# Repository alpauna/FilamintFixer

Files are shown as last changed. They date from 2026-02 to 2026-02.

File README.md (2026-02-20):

# FilamintFixer

ESP32-based automatic filament jam detector and unsticker for 3D printers. Detects when filament is jammed or pinched on the spool and mechanically yanks it free — no missed prints, no babysitting.

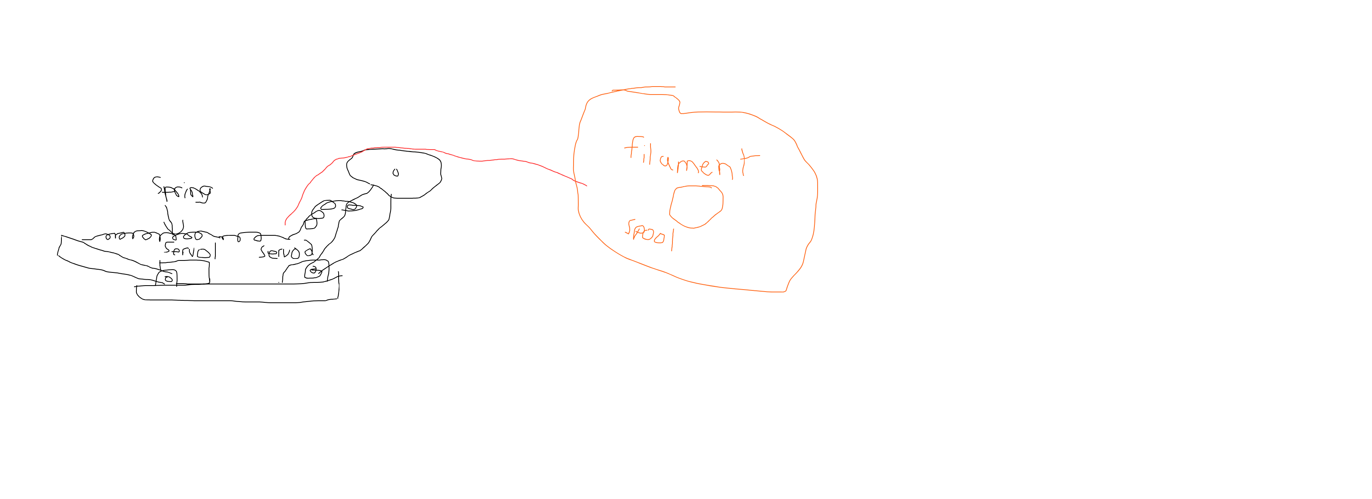
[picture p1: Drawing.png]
Concept Drawing


## How It Works

A spring-loaded feed arm guides filament from the spool to the extruder through a grooved wheel. When filament flows normally, the arm floats at its rest angle. When filament jams on the spool, the extruder's pull increases tension on the spring, pulling the arm down. When the angle drops below a threshold, a servo activates and yanks the filament free.

### Key Features

- **Automatic jam detection** via potentiometer angle feedback (primary) and reed switch filament movement detection (secondary)
- **Servo detach/attach pattern** — feed arm servo is detached during normal printing so the arm floats freely with spring tension, only attaching to actuate
- **Adjustable spring tension** — second servo locks in position to set baseline spring tension
- **Serial command interface** for tuning parameters and pot calibration
- **3D printable** — OpenSCAD parametric models included for all mechanical parts

## Bill of Materials

### Electronics (DigiKey)

| Part | DigiKey P/N | Qty | ~Price | Notes |
|---|---|-----|---|---|
| ESP32-S3-DEVKITC-1-N8R8 | [2768-ESP32-S3-DEVKITC-1-N8R8-ND](https://www.digikey.com/en/products/detail/espressif-systems/ESP32-S3-DEVKITC-1-N8R8/15295894) | 1 | $15.00 | 8MB Flash + 8MB PSRAM. Any ESP32 with ADC works |
| Standard Metal Gear Servo | [1528-1083-ND](https://www.digikey.com/en/products/detail/adafruit-industries-llc/1142/5154658) | 2 | $19.95 | Adafruit 1142. Or MG996R from Amazon (~$8/pair) |
| 10K Pot, D-shaft, Linear | [987-1308-ND](https://www.digikey.com/en/products/detail/tt-electronics-bi/P160KN-0QD15B10K/2408885) | 2 | $1.59 | TT Electronics P160KN-0QD15B10K. Must be "QD" (D-shaft) |
| Reed Switch, Glass, NO | [HE502-ND](https://www.digikey.com/en/products/detail/littelfuse-inc/MDSR-4-12-23/200302) | 1 | $1.50 | Littelfuse MDSR-4-12-23 |
| Neodymium Disc Magnet 6x3mm | [469-1017-ND](https://www.digikey.com/en/products/detail/radial-magnets-inc/8996/5126078) | 1 | $0.30 | Radial Magnets 8996 |
| 625ZZ Ball Bearing | [1188-BEARING-625ZZ-ND](https://www.digikey.com/en/products/detail/olimex-ltd/BEARING-625ZZ/21662104) | 2 | $0.82 | 5mm bore, 16mm OD, 5mm width |

### Mechanical (Amazon / McMaster-Carr)

| Part | Qty | ~Price | Notes |
|---|-----|---|---|
| Extension spring, 30-50mm, light tension | 1 | $3 | Connects feed arm to tension arm |
| M5x30mm bolt + nut | 1 | $0.50 | Guide wheel axle |
| M3/M4 screw & nut assortment | 1 kit | $12 | Mounting hardware |

**Estimated total: $45-55** (with Amazon MG996R servos) or **~$85** (all from DigiKey)

## Building

This is a [PlatformIO](https://platformio.org/) project targeting ESP32-S3.

```bash
# Build
pio run -e freenove_esp32_s3_wroom

# Upload
pio run -t upload -e freenove_esp32_s3_wroom

# Monitor serial output
pio run -t monitor -e freenove_esp32_s3_wroom
```

## 3D Printed Parts

STL files are in the `cad/` directory. Source files are parametric OpenSCAD — edit `common.scad` to adjust dimensions for different servos or potentiometers.

| Part | File | Description |
|---|---|---|
| Base | `base.stl` | Holds both servos side-by-side, pot mounting pads, reed switch mount |
| Feed Arm | `feed_arm.stl` | 120mm arm with 25T spline bore, spring anchor, wheel axle, filament retainer |
| Tension Arm | `tension_arm.stl` | 50mm arm with 25T spline bore, spring anchor at tip |
| Guide Wheel | `guide_wheel.stl` | 25mm grooved wheel with 625ZZ bearing pockets |

To regenerate STLs from source:
```bash
cd cad
openscad -o base.stl base.scad
openscad -o feed_arm.stl feed_arm.scad
openscad -o tension_arm.stl tension_arm.scad
openscad -o guide_wheel.stl guide_wheel.scad
```

## Serial Commands

| Command | Description |
|---|---|
| `u` | Manual unstick trigger |
| `t <angle>` | Set tension servo angle |
| `j <angle>` | Set jam threshold angle |
| `r <angle>` | Set rest angle |
| `c` | Pot calibration (prints raw ADC for 5 sec) |
| `s` | Print status |
| `h` | Help |

## License

MIT

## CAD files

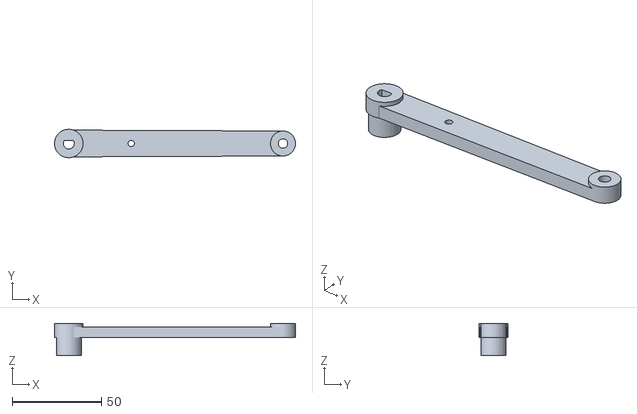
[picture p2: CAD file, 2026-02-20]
cad/feed_arm.stl
135.0 x 16.0 x 18.0

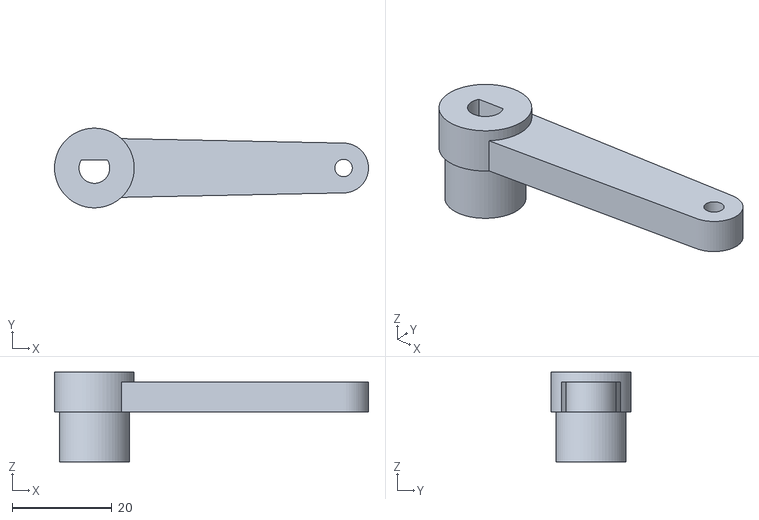
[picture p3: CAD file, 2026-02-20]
cad/tension_arm.stl
63.0 x 16.0 x 18.0

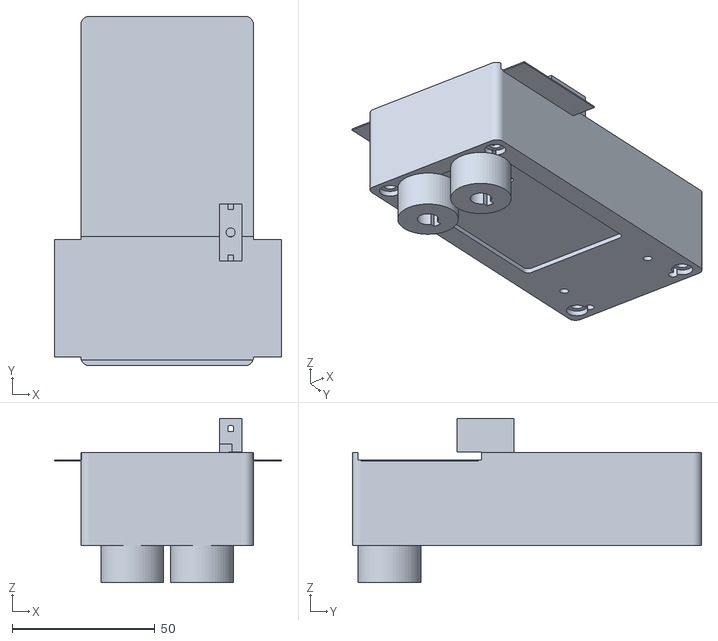
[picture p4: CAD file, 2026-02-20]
cad/base.stl
79.5 x 122.4 x 57.5

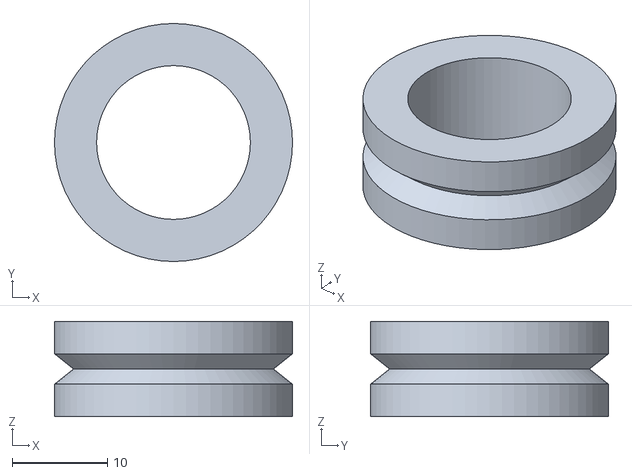
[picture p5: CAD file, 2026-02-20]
cad/guide_wheel.stl
25.0 x 25.0 x 10.0

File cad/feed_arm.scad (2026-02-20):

// feed_arm.scad — Main feed arm that attaches to Servo0
// 120mm from servo shaft to guide wheel center.
// Spring anchor point partway along the arm.
// Blind 25T spline bore couples directly to servo output shaft.

include <common.scad>

// --- Arm Parameters ---
arm_length = 120;           // shaft center to wheel center
arm_width = 15;             // arm cross-section width
arm_thickness = 6;          // arm cross-section height
hub_dia = 16;               // hub outer diameter
hub_height = 8;             // hub thickness above arm

// Spring anchor — hole for spring hook, partway along the arm
spring_anchor_dist = 35;    // distance from shaft center
spring_hole_dia = 3.5;      // spring wire hook hole

// Guide wheel axle at the tip
wheel_axle_dia = 5.0;       // axle hole diameter (for M5 bolt or 5mm shaft)
wheel_mount_dia = 14;       // boss around axle

// --- Filament Retainer ---
// L-shaped guard over the guide wheel groove to prevent filament from
// jumping out during unsticking. Bridge plate spans from boss top over
// the wheel, vertical wall drops down at the outer radius to cover the groove.
// Tapered inlet on one end for easy filament threading.

// Guide wheel references (must match guide_wheel.scad)
wheel_od     = 25;          // wheel outer diameter
wheel_width  = 10;          // wheel width (Z)
wheel_z_off  = -3;          // wheel bottom Z relative to arm Z=0 (match assembly)

// Retainer tuning
ret_gap      = 2.0;         // radial clearance between wheel rim and retainer wall
ret_wall     = 2.0;         // shell/plate thickness
ret_arc_len  = 15.0;        // arc coverage over wheel outer edge (mm)
ret_drop     = 8.0;         // how far wall drops below bridge to cover groove
ret_taper_len   = 8.0;      // inlet taper arc length (mm)
ret_taper_flare = 4.0;      // extra radial gap at taper mouth

// Derived
ret_ir       = wheel_od / 2 + ret_gap;                     // inner radius from wheel center
ret_or       = ret_ir + ret_wall;                           // outer radius
ret_arc_deg  = ret_arc_len / ret_ir * 57.2958;             // arc in degrees
ret_tap_deg  = ret_taper_len / ret_ir * 57.2958;           // taper arc in degrees
ret_bridge_z = arm_thickness + 2;                           // bridge plate Z = boss top
ret_wall_bot = ret_bridge_z - ret_drop;                     // bottom of retainer wall
ret_plate_r0 = wheel_mount_dia / 2 - 1;                    // bridge plate inner radius
ret_plate_w  = ret_or - ret_plate_r0;                       // bridge plate radial width

// Servo screw hole through hub (M3 to secure to servo horn)
horn_screw_dia = m3_hole;

// --- Filament retainer module ---
// Generates an L-shaped guard at the tip of the arm over the guide wheel.
// The bridge plate sits on the boss top (above the wheel), the vertical
// wall drops down at the outer radius to cover the groove.
module filament_retainer() {
    translate([arm_length, 0, 0]) {
        // Main arc: L-shaped cross-section swept around wheel outer edge.
        // Arc centered on +X direction (outer rim, away from arm body).
        // Single polygon avoids coincident-face manifold warnings.
        rotate([0, 0, -ret_arc_deg / 2])
            rotate_extrude(angle = ret_arc_deg)
                polygon([
                    [ret_plate_r0, ret_bridge_z],                // bridge inner bottom
                    [ret_plate_r0, ret_bridge_z + ret_wall],     // bridge inner top
                    [ret_or,       ret_bridge_z + ret_wall],     // bridge outer top
                    [ret_or,       ret_wall_bot],                // wall outer bottom
                    [ret_ir,       ret_wall_bot],                // wall inner bottom
                    [ret_ir,       ret_bridge_z]                 // L corner
                ]);

        // Inlet taper on +Y end: L-shaped cross-section flares outward.
        // Overlap 1 degree into main arc to avoid coincident-face warnings.
        hull() {
            rotate([0, 0, ret_arc_deg / 2 - 1])
                translate([ret_plate_r0, 0, ret_wall_bot])
                    cube([ret_plate_w, 0.01, ret_bridge_z + ret_wall - ret_wall_bot]);
            rotate([0, 0, ret_arc_deg / 2 + ret_tap_deg])
                translate([ret_plate_r0, 0, ret_wall_bot])
                    cube([ret_plate_w + ret_taper_flare, 0.01,
                          ret_bridge_z + ret_wall - ret_wall_bot]);
        }
    }
}

module feed_arm() {
    difference() {
        union() {
            // Hub (attaches to servo 25T spline)
            cylinder(d=hub_dia, h=hub_height);

            // Arm body — tapered from hub to wheel mount
            hull() {
                // At hub
                translate([0, -arm_width/2, 0])
                    cube([0.1, arm_width, arm_thickness]);
                // At wheel mount
                translate([arm_length, 0, 0])
                    cylinder(d=wheel_mount_dia, h=arm_thickness);
            }

            // Wheel mount boss (thicker)
            translate([arm_length, 0, 0])
                cylinder(d=wheel_mount_dia, h=arm_thickness + 2);

            // Spring anchor boss
            translate([spring_anchor_dist, 0, 0])
                cylinder(d=10, h=arm_thickness);

            // Filament retainer (guard over guide wheel groove)
            filament_retainer();
        }

        // Blind spline bore (25T servo spline coupling)
        translate([0, 0, -0.1])
            cylinder(d=servo_spline_bore, h=spline_engage_depth + 0.1);

        // Horn screw hole (through hub center, for M3 screw into servo)
        translate([0, 0, -0.1])
            cylinder(d=horn_screw_dia, h=hub_height + 0.2);

        // Guide wheel axle hole
        translate([arm_length, 0, -0.1])
            cylinder(d=wheel_axle_dia + tol, h=arm_thickness + 3);

        // Spring anchor hole (vertical, for spring hook)
        translate([spring_anchor_dist, 0, -0.1])
            cylinder(d=spring_hole_dia, h=arm_thickness + 1);
    }
}

feed_arm();

echo("=== Feed Arm ===");
echo(str("Length: ", arm_length, " mm"));
echo(str("Hub OD: ", hub_dia, " mm"));
echo(str("Spline bore: ", servo_spline_bore, " mm x ", spline_engage_depth, " mm deep"));
echo(str("Spring anchor at: ", spring_anchor_dist, " mm from shaft"));

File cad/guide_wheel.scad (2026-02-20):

// guide_wheel.scad — Filament guide wheel with groove
// Mounts at the tip of the feed arm on an axle.
// Has a V-groove to guide the filament.
// Designed for a rotary encoder or simply free-spinning on a bolt.

include <common.scad>

// --- Wheel Parameters ---
wheel_od = 25;              // outer diameter
wheel_width = 10;           // total width
groove_depth = 2.5;         // how deep the V-groove cuts into the OD
groove_width = 4;           // groove width at the rim
groove_angle = 60;          // V-groove angle

axle_dia = 5.0;             // M5 bolt or 5mm shaft
bearing_od = 16;            // 625ZZ bearing OD (if using bearing) or just clearance
bearing_h = 5;              // bearing width
use_bearing = true;         // set false for plain bore

// Encoder magnet pocket (for AS5600 or similar magnetic encoder)
magnet_dia = 6.2;           // 6mm diametric magnet
magnet_depth = 3;

module guide_wheel() {
    difference() {
        union() {
            // Main wheel body
            cylinder(d=wheel_od, h=wheel_width);
        }

        // V-groove around the circumference
        translate([0, 0, wheel_width/2])
            rotate_extrude()
                translate([wheel_od/2 - groove_depth + 0.5, 0, 0])
                    polygon([
                        [groove_depth, -groove_width/2],
                        [0, 0],
                        [groove_depth, groove_width/2]
                    ]);

        // Axle bore
        if (use_bearing) {
            // Bearing pocket (press fit from each side)
            translate([0, 0, -0.1])
                cylinder(d=bearing_od + tol_tight, h=bearing_h + 0.1);
            translate([0, 0, wheel_width - bearing_h])
                cylinder(d=bearing_od + tol_tight, h=bearing_h + 0.2);
            // Through hole for axle
            translate([0, 0, -0.1])
                cylinder(d=axle_dia + tol, h=wheel_width + 1);
        } else {
            // Plain bore with clearance
            translate([0, 0, -0.1])
                cylinder(d=axle_dia + tol*2, h=wheel_width + 1);
        }

        // Encoder magnet pocket (top face, centered)
        translate([0, 0, wheel_width - magnet_depth])
            cylinder(d=magnet_dia, h=magnet_depth + 0.1);
    }
}

guide_wheel();

echo("=== Guide Wheel ===");
echo(str("OD: ", wheel_od, " mm"));
echo(str("Width: ", wheel_width, " mm"));
echo(str("Axle: ", axle_dia, " mm"));
echo(str("Bearing: ", use_bearing ? "625ZZ" : "plain bore"));

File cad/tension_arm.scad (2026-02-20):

// tension_arm.scad — Tension arm that attaches to Servo1
// Shorter arm that anchors the other end of the spring.
// Servo1 holds this arm locked during printing to set spring tension.
// Blind 25T spline bore couples directly to servo output shaft.

include <common.scad>

// --- Arm Parameters ---
arm_length = 50;            // shorter than feed arm
arm_width = 12;
arm_thickness = 6;
hub_dia = 16;
hub_height = 8;
horn_screw_dia = m3_hole;

// Spring anchor at the tip
spring_hole_dia = 3.5;      // same as feed arm spring hole

module tension_arm() {
    difference() {
        union() {
            // Hub (attaches to servo 25T spline)
            cylinder(d=hub_dia, h=hub_height);

            // Arm body
            hull() {
                translate([0, -arm_width/2, 0])
                    cube([0.1, arm_width, arm_thickness]);
                translate([arm_length, 0, 0])
                    cylinder(d=10, h=arm_thickness);
            }

            // Tip boss
            translate([arm_length, 0, 0])
                cylinder(d=10, h=arm_thickness);
        }

        // Blind spline bore (25T servo spline coupling)
        translate([0, 0, -0.1])
            cylinder(d=servo_spline_bore, h=spline_engage_depth + 0.1);

        // Horn screw hole (through hub center, for M3 screw into servo)
        translate([0, 0, -0.1])
            cylinder(d=horn_screw_dia, h=hub_height + 0.2);

        // Spring anchor hole at tip
        translate([arm_length, 0, -0.1])
            cylinder(d=spring_hole_dia, h=arm_thickness + 1);
    }
}

tension_arm();

echo("=== Tension Arm ===");
echo(str("Length: ", arm_length, " mm"));
echo(str("Spline bore: ", servo_spline_bore, " mm x ", spline_engage_depth, " mm deep"));

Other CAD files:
cad/assembly.scad
cad/base.scad
cad/common.scad

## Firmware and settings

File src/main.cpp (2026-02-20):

#include <Arduino.h>
#include "pins.h"
#include "Config.h"
#include "WheelEncoder.h"
#include "FeedArmController.h"

Config config;
ReedSwitch reedSwitch;
FeedArmController feedArm;

uint32_t lastMonitorUpdate = 0;
uint32_t lastStatusPrint = 0;

// --- Serial Command Handler ---
//   u            - manual unstick trigger
//   t <angle>    - set tension servo angle
//   j <angle>    - set jam threshold angle
//   r <angle>    - set rest angle
//   c            - pot calibration mode (prints raw ADC values)
//   s            - print current status
//   h            - help
void handleSerial() {
    if (!Serial.available()) return;

    String line = Serial.readStringUntil('\n');
    line.trim();
    if (line.length() == 0) return;

    char cmd = line.charAt(0);

    switch (cmd) {
    case 'u':
    case 'U':
        feedArm.triggerUnstick();
        break;

    case 't':
    case 'T': {
        float angle = line.substring(1).toFloat();
        if (angle > 0) {
            feedArm.setTensionAngle(angle);
            config.tensionServoAngle = angle;
        } else {
            Serial.printf("Tension angle: cmd=%.0f° actual=%.0f°\n",
                          feedArm.tensionAngle(), feedArm.tensionArmAngle());
        }
        break;
    }

    case 'j':
    case 'J': {
        float angle = line.substring(1).toFloat();
        if (angle > 0) {
            config.feedArmJamAngle = angle;
            feedArm.updateConfig(config);
            Serial.printf("Jam threshold set to %.0f°\n", angle);
        }
        break;
    }

    case 'r':
    case 'R': {
        float angle = line.substring(1).toFloat();
        if (angle > 0) {
            config.feedArmRestAngle = angle;
            feedArm.updateConfig(config);
            Serial.printf("Rest angle set to %.0f°\n", angle);
        }
        break;
    }

    case 'c':
    case 'C':
        // Pot calibration: print raw ADC values for 5 seconds.
        Serial.println("=== Pot Calibration (5 sec) ===");
        Serial.println("Move arms to their endpoints and note the ADC values.");
        Serial.println("Update potFeedMin/Max and potTensionMin/Max in Config.h");
        for (int i = 0; i < 50; i++) {
            Serial.printf("  Feed: raw=%4d -> %.0f°  |  Tension: raw=%4d -> %.0f°\n",
                          feedArm.rawFeedPot(), feedArm.feedArmAngle(),
                          feedArm.rawTensionPot(), feedArm.tensionArmAngle());
            delay(100);
        }
        Serial.println("=== Calibration done ===");
        break;

    case 's':
    case 'S':
        Serial.println("=== Feed Arm Status ===");
        Serial.printf("  State:           %s\n", feedArmStateName(feedArm.state()));
        Serial.printf("  Feed arm angle:  %.0f° (pot raw: %d)\n",
                      feedArm.feedArmAngle(), feedArm.rawFeedPot());
        Serial.printf("  Tension angle:   %.0f° cmd / %.0f° actual (pot raw: %d)\n",
                      feedArm.tensionAngle(), feedArm.tensionArmAngle(),
                      feedArm.rawTensionPot());
        Serial.printf("  Reed pulses:     %u total, %.1f/sec\n",
                      reedSwitch.pulseCount(), reedSwitch.pulsesPerSec());
        Serial.printf("  Filament stall:  %s (last pulse %ums ago)\n",
                      feedArm.filamentStalled() ? "YES" : "no",
                      reedSwitch.timeSinceLastPulseMs());
        Serial.printf("  Unstick count:   %u\n", feedArm.unstickCount());
        Serial.printf("  Jam threshold:   %.0f°\n", config.feedArmJamAngle);
        Serial.printf("  Rest angle:      %.0f°\n", config.feedArmRestAngle);
        Serial.printf("  Unstick angle:   %.0f°\n", config.feedArmUnstickAngle);
        break;

    case 'h':
    case 'H':
    case '?':
        Serial.println("=== Commands ===");
        Serial.println("  u          - Manual unstick trigger");
        Serial.println("  t <angle>  - Set tension servo angle (spring calibration)");
        Serial.println("  j <angle>  - Set jam threshold angle");
        Serial.println("  r <angle>  - Set rest angle");
        Serial.println("  c          - Pot calibration (prints raw ADC for 5 sec)");
        Serial.println("  s          - Print status");
        Serial.println("  h          - This help");
        break;

    default:
        Serial.printf("Unknown command: '%c'. Type 'h' for help.\n", cmd);
        break;
    }
}

void setup() {
    Serial.begin(config.baudRate);
    delay(1000);

    Serial.println();
    Serial.println("================================");
    Serial.println("  3D Printer Feed Arm v0.2");
    Serial.println("  Pot Angle + Reed Switch");
    Serial.println("================================");

    // Status LED.
    pinMode(PIN_STATUS_LED, OUTPUT);
    digitalWrite(PIN_STATUS_LED, LOW);

    // Initialize reed switch (filament wheel rotation).
    reedSwitch.begin(PIN_REED_SWITCH);
    Serial.println("[Main] Reed switch initialized.");

    // Initialize feed arm controller with pot pins and reed switch.
    feedArm.begin(config, PIN_SERVO_FEED_ARM, PIN_SERVO_TENSION,
                  PIN_POT_FEED_ARM, PIN_POT_TENSION, &reedSwitch);
    Serial.println("[Main] Feed arm controller initialized.");

    Serial.println("[Main] Ready. Type 'h' for commands.");
    Serial.println();
}

void loop() {
    uint32_t now = millis();

    // Run feed arm monitor at configured interval.
    if (now - lastMonitorUpdate >= config.monitorIntervalMs) {
        feedArm.update();
        lastMonitorUpdate = now;

        // Blink LED based on state.
        if (feedArm.state() == FeedArmState::MONITORING) {
            // Slow heartbeat in normal operation.
            // Fast blink if filament stalled (warning).
            if (feedArm.filamentStalled()) {
                digitalWrite(PIN_STATUS_LED, (now / 250) % 2 == 0);
            } else {
                digitalWrite(PIN_STATUS_LED, (now / 1000) % 2 == 0);
            }
        } else if (feedArm.state() == FeedArmState::UNSTICKING ||
                   feedArm.state() == FeedArmState::HOLD_UNSTICK) {
            // Rapid blink during unstick action.
            digitalWrite(PIN_STATUS_LED, (now / 100) % 2 == 0);
        } else {
            digitalWrite(PIN_STATUS_LED, LOW);
        }
    }

    // Periodic status print (every 5 seconds).
    if (now - lastStatusPrint >= 5000) {
        Serial.printf("[Status] %s | Angle:%.0f° | Reed:%.1f/s | Unsticks:%u%s\n",
                      feedArmStateName(feedArm.state()),
                      feedArm.feedArmAngle(),
                      reedSwitch.pulsesPerSec(),
                      feedArm.unstickCount(),
                      feedArm.filamentStalled() ? " STALL" : "");
        lastStatusPrint = now;
    }

    // Handle serial commands.
    handleSerial();
}

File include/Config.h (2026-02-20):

#pragma once

#include <cstdint>

// All angles in degrees (0-160 range for 160-degree servos).
// All times in milliseconds unless noted.

struct Config {
    // --- Feed Arm ---
    // Resting angle: where the spring holds the arm under normal filament tension.
    // This is the "home" position during normal printing.
    float feedArmRestAngle = 90.0f;

    // Jam threshold: when the arm is pulled past this angle by extruder tension
    // (filament stuck on spool), trigger the unstick action.
    // Lower angle = more tension pulling the arm toward the spool.
    float feedArmJamAngle = 45.0f;

    // Unstick angle: the servo drives to this angle to yank filament away from spool.
    float feedArmUnstickAngle = 140.0f;

    // How long to hold the unstick position before returning to rest (ms).
    uint32_t unstickHoldTimeMs = 500;

    // Cooldown between unstick attempts to avoid hammering (ms).
    uint32_t unstickCooldownMs = 2000;

    // --- Tension Arm (Spring Adjustment) ---
    // Servo angle that sets the spring's effective length.
    // Higher angle = more spring compression = more tension on feed arm.
    // Adjust this to match your spool's normal drag friction.
    // Tension servo STAYS LOCKED at this angle during printing.
    float tensionServoAngle = 80.0f;

    // Min/max bounds for tension calibration.
    float tensionAngleMin = 30.0f;
    float tensionAngleMax = 130.0f;

    // --- Potentiometer Angle Reading ---
    // ADC range mapping: what ADC values correspond to 0° and 160°.
    // Calibrate by manually moving arm to known angles and reading ADC.
    uint16_t potFeedMin = 200;       // ADC value at 0° (full one direction)
    uint16_t potFeedMax = 3800;      // ADC value at 160° (full other direction)
    uint16_t potTensionMin = 200;
    uint16_t potTensionMax = 3800;

    // Potentiometer smoothing: number of samples to average.
    uint8_t potSamples = 8;

    // --- Reed Switch (Filament Movement Detection) ---
    // If no reed switch pulses within this window, filament has stalled.
    uint32_t reedStallTimeoutMs = 3000;

    // Minimum pulses per second during active printing.
    // Below this = suspicious (slow feed or stall).
    float reedMinPulsesPerSec = 0.5f;

    // --- General ---
    // How often the main monitor loop runs (ms).
    uint32_t monitorIntervalMs = 50;

    // Serial baud rate.
    uint32_t baudRate = 115200;
};

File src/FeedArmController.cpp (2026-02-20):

#include "FeedArmController.h"

const char* feedArmStateName(FeedArmState state) {
    switch (state) {
        case FeedArmState::MONITORING:   return "MONITORING";
        case FeedArmState::UNSTICKING:   return "UNSTICKING";
        case FeedArmState::HOLD_UNSTICK: return "HOLD_UNSTICK";
        case FeedArmState::RETURNING:    return "RETURNING";
        case FeedArmState::COOLDOWN:     return "COOLDOWN";
        default:                         return "UNKNOWN";
    }
}

void FeedArmController::begin(const Config& cfg, uint8_t feedServoPin,
                               uint8_t tensionServoPin, uint8_t feedPotPin,
                               uint8_t tensionPotPin, ReedSwitch* reed) {
    _cfg = cfg;
    _reed = reed;
    _feedServoPin = feedServoPin;
    _tensionServoPin = tensionServoPin;
    _feedPotPin = feedPotPin;
    _tensionPotPin = tensionPotPin;

    // Configure ADC pins for potentiometers.
    analogReadResolution(12);       // 0-4095
    analogSetAttenuation(ADC_11db); // 0-3.3V range
    pinMode(_feedPotPin, INPUT);
    pinMode(_tensionPotPin, INPUT);

    // Tension servo: attach and hold position (stays locked during printing).
    _tensionServo.setPeriodHertz(50);
    _tensionServo.attach(_tensionServoPin, 500, 2500);
    _tensionAngle = _cfg.tensionServoAngle;
    _tensionServo.write((int)_tensionAngle);

    // Feed servo: configure but start DETACHED.
    // During monitoring, the arm floats freely with the spring.
    // The pot reads the actual angle.
    _feedServo.setPeriodHertz(50);
    _feedServoAttached = false;
    // Don't attach yet — arm should float in MONITORING state.

    _state = FeedArmState::MONITORING;
    _stateEnteredAt = millis();
    _lastReedSampleTime = millis();
    _unstickCount = 0;

    // Read initial angles from pots.
    _feedArmAngle = readPotAngle(_feedPotPin, _cfg.potFeedMin, _cfg.potFeedMax);
    _tensionArmAngle = readPotAngle(_tensionPotPin, _cfg.potTensionMin, _cfg.potTensionMax);

    Serial.printf("[FeedArm] Init. Feed pot=%.0f° Tension pot=%.0f°\n",
                  _feedArmAngle, _tensionArmAngle);
    Serial.printf("[FeedArm] Jam threshold=%.0f° Unstick=%.0f° Tension cmd=%.0f°\n",
                  _cfg.feedArmJamAngle, _cfg.feedArmUnstickAngle, _tensionAngle);
    Serial.printf("[FeedArm] Feed servo DETACHED (arm floating with spring)\n");
}

void FeedArmController::update() {
    uint32_t now = millis();
    uint32_t elapsed = now - _stateEnteredAt;

    // Always read pot angles — gives actual arm position regardless of servo state.
    _feedArmAngle = readPotAngle(_feedPotPin, _cfg.potFeedMin, _cfg.potFeedMax);
    _tensionArmAngle = readPotAngle(_tensionPotPin, _cfg.potTensionMin, _cfg.potTensionMax);

    // Sample reed switch periodically.
    if (now - _lastReedSampleTime >= 1000) {
        if (_reed) {
            _reed->sample();
            _filamentStalled = _reed->isStalled(_cfg.reedStallTimeoutMs);
        }
        _lastReedSampleTime = now;
    }

    switch (_state) {

    case FeedArmState::MONITORING:
        // Feed servo is DETACHED. Arm floats with spring.
        // Pot reads actual arm angle driven by spring tension vs filament pull.
        // Jam detection: angle drops below threshold (filament pulling arm toward spool).
        if (isJamDetected()) {
            Serial.printf("[FeedArm] JAM! Arm angle=%.0f° (threshold=%.0f°) stall=%s\n",
                          _feedArmAngle, _cfg.feedArmJamAngle,
                          _filamentStalled ? "YES" : "no");
            transitionTo(FeedArmState::UNSTICKING);
        }
        break;

    case FeedArmState::UNSTICKING:
        // Relax tension servo first so feed arm doesn't fight spring + jam.
        // Then attach feed servo and drive to unstick angle.
        if (!_feedServoAttached) {
            _savedTensionAngle = _tensionAngle;
            _tensionServo.write((int)_cfg.tensionAngleMin);
            Serial.printf("[FeedArm] Tension relaxed: %.0f° -> %.0f° (min)\n",
                          _savedTensionAngle, _cfg.tensionAngleMin);

            _feedServo.attach(_feedServoPin, 500, 2500);
            _feedServoAttached = true;
            Serial.println("[FeedArm] Servo ATTACHED — driving to unstick angle");
        }
        _feedServo.write((int)_cfg.feedArmUnstickAngle);
        transitionTo(FeedArmState::HOLD_UNSTICK);
        break;

    case FeedArmState::HOLD_UNSTICK:
        // Hold the unstick position for the configured duration.
        // Servo stays attached and holding.
        if (elapsed >= _cfg.unstickHoldTimeMs) {
            transitionTo(FeedArmState::RETURNING);
        }
        break;

    case FeedArmState::RETURNING:
        // Drive back to rest angle, then detach.
        _feedServo.write((int)_cfg.feedArmRestAngle);
        _unstickCount++;
        Serial.printf("[FeedArm] Unstick #%u complete. Returning to %.0f°\n",
                      _unstickCount, _cfg.feedArmRestAngle);
        transitionTo(FeedArmState::COOLDOWN);
        break;

    case FeedArmState::COOLDOWN:
        // Wait before detaching servo and returning to monitoring.
        // Keep servo attached briefly so it reaches rest position.
        if (elapsed >= _cfg.unstickCooldownMs) {
            // Detach feed servo — arm floats with spring again.
            if (_feedServoAttached) {
                _feedServo.detach();
                _feedServoAttached = false;
                Serial.println("[FeedArm] Servo DETACHED — back to monitoring");
            }
            // Restore tension servo to its pre-unstick angle.
            _tensionAngle = _savedTensionAngle;
            _tensionServo.write((int)_tensionAngle);
            Serial.printf("[FeedArm] Tension restored to %.0f°\n", _tensionAngle);
            // Reset reed switch to avoid false stall after unstick action.
            if (_reed) _reed->reset();
            transitionTo(FeedArmState::MONITORING);
        }
        break;
    }
}

void FeedArmController::triggerUnstick() {
    if (_state == FeedArmState::MONITORING || _state == FeedArmState::COOLDOWN) {
        Serial.println("[FeedArm] Manual unstick triggered.");
        transitionTo(FeedArmState::UNSTICKING);
    }
}

void FeedArmController::setTensionAngle(float angle) {
    _tensionAngle = constrain(angle, _cfg.tensionAngleMin, _cfg.tensionAngleMax);
    _tensionServo.write((int)_tensionAngle);
    Serial.printf("[FeedArm] Tension set to %.0f°\n", _tensionAngle);
}

float FeedArmController::filamentPulsesPerSec() const {
    return _reed ? _reed->pulsesPerSec() : 0;
}

void FeedArmController::transitionTo(FeedArmState newState) {
    if (newState != _state) {
        Serial.printf("[FeedArm] %s -> %s\n",
                      feedArmStateName(_state), feedArmStateName(newState));
    }
    _state = newState;
    _stateEnteredAt = millis();
}
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

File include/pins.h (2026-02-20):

#pragma once

// ESP32-S3 WROOM pin map.
// GPIO 26-37 are RESERVED (internal flash/PSRAM on WROOM-N8R8).
// GPIO 19-20 are USB D-/D+ (used for serial/JTAG).

// --- Servo Pins ---
// Feed arm servo: the main arm that filament rides on.
// Actuates to yank filament free when jam is detected.
// DETACHED during monitoring so arm floats with spring tension.
#define PIN_SERVO_FEED_ARM      13

// Tension arm servo: adjusts spring effective length
// to calibrate normal spool friction baseline.
// STAYS ATTACHED during printing — holds position.
#define PIN_SERVO_TENSION       14

// --- Potentiometer Pins (angle feedback via ADC) ---
// 10k linear pots on each arm pivot, D-shaft coupled.
// Reads actual arm angle (not servo-commanded position).
#define PIN_POT_FEED_ARM        6   // ADC1_CH5
#define PIN_POT_TENSION         7   // ADC1_CH6

// --- Reed Switch (filament wheel rotation detection) ---
// Magnet on guide wheel, reed switch on arm/mount.
// One pulse per revolution = filament is moving.
#define PIN_REED_SWITCH         4   // interrupt capable

// --- Status LED (Freenove onboard RGB is GPIO 48) ---
#define PIN_STATUS_LED          2

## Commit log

2026-02-20 Initial commit: FilamintFixer v0.2
    ESP32-based automatic filament jam detector and unsticker for 3D printers.
    Dual MG996R servos with potentiometer angle feedback (D-shaft coupling),
    reed switch filament movement detection, and 3D printable OpenSCAD parts.
    [assembly.scad, base.scad, base.stl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]
2026-02-20 Add DigiKey BOM to README, fix upload port to ttyUSB0
2026-02-20 Redesign base and arm coupling: spline bore, fix dimensions
    Base plate: fix base_l formula (servos are side-by-side, not
    front-to-back), add 5mm lip above servo tabs, remove physically
    impossible coaxial pot towers and shaft clearance holes, add flat
    pot mounting pads on base surface for future sensor bracket,
    increase tab supports from 0.5mm to 2.0mm.
    Arms: replace D-shaft bore and extension (pot coupling through
    servo body is impossible) with blind 25T spline bore that couples
    directly to servo output shaft. Add filament retainer to feed arm
    parts table in README.
    Firmware: relax tension servo during unstick so feed arm doesn't
    fight spring tension plus the jam simultaneously.
    Co-Author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
    [assembly.scad, base.scad, common.scad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]
